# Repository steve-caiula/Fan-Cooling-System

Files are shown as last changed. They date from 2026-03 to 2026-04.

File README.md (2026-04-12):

# Fan Cooling System - Bare-Metal AVR

A bare-metal C project for the ATmega328P. Implements custom 1-Wire and I2C drivers, 
PWM fan control and tachometer reading via hardware timers and interrupts. No external libraries.

## Overview

This project implements a temperature-based fan cooling system on an ATmega328P microcontroller.
A DS18B20 sensor continuously measures the ambient temperature and adjusts the fan speed accordingly
via PWM, across four operating modes: Silent, Normal, Performance and Max. The system monitors fan RPM
via tachometer input and detects faults such as fan stall, underspeed and sensor disconnection.
Errors are signaled through a 20x4 I2C LCD display, a passive buzzer and four status LEDs, each with
a dedicated alarm priority. All drivers are implemented from scratch via direct register manipulation,
using only the avr-gcc toolchain.

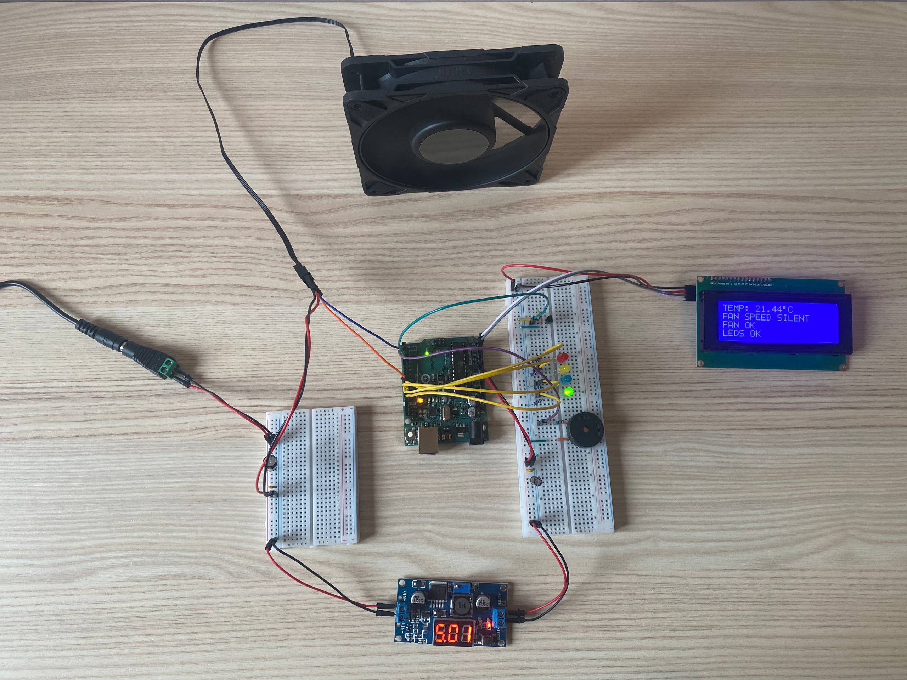
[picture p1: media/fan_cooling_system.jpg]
System


For the video demo, see the `media/` folder.

## Hardware

The system is built around an Arduino UNO R3 (ATmega328P) connected to a DS18B20 temperature sensor,
an Arctic P12 PRO PWM fan, a 20x4 I2C LCD display and a passive piezo buzzer. The circuit is powered
by a 12V supply with a DC-DC step-down module providing 5V to the MCU and peripherals. The fan is
driven directly at 12V. The circuit is currently assembled on a breadboard.

### Components

| **Component** | **Quantity** | **Notes** |
| :--- | :--- | :--- |
| Arduino UNO R3 | 1 | ATmega328P @ 16MHz |
| Arctic P12 PRO | 1 | 4-pin PWM fan, 12V |
| DS18B20 | 1 | 1-Wire temperature sensor |
| NHD-0420H1Z | 1 | 20x4 LCD with PCF8574 I2C module |
| Murata Buzzer | 1 | Passive piezo buzzer |
| LED | 4 | Red, Yellow, Blue, Green |
| DC-DC Step-Down Module | 1 | 12V → 5V (adjustable) |
| 12V Power Supply | 1 | |
| Capacitor 47µF 25V | 1 | Electrolytic, power supply decoupling |
| Capacitor 330µF 25V | 1 | Electrolytic, fan power decoupling |
| Capacitor 100nF | 2 | Ceramic, decoupling |
| Resistor 4.7kΩ | 1 | 1-Wire bus pull-up |
| Resistor 100Ω | 1 | Buzzer current limiting |
| Resistor 220Ω | 4 | LED current limiting |
| Breadboard | 2 | 830 tie points, 380 tie points |
| Jumper Wires | 22 | |

### Schematic

The KiCad project file and a PDF export are available in the `hardware/` folder.

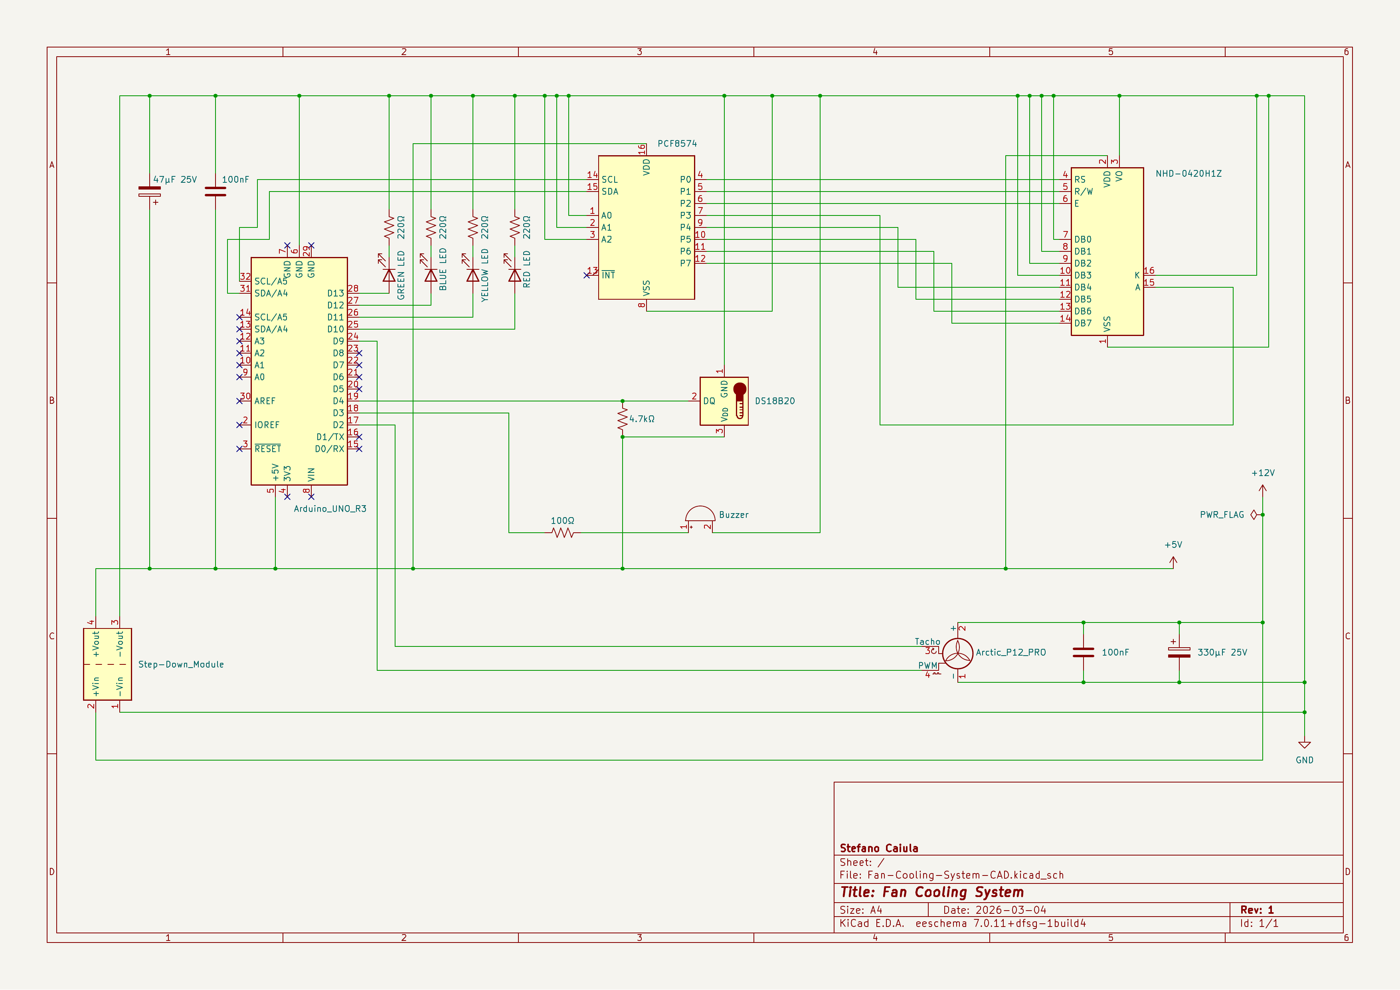
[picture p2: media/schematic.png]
Schematic


## Software

The firmware is organized into independent, single-responsibility modules. Each peripheral has a dedicated
driver with a clean public interface, keeping hardware-specific code separate from application logic.

### Structure

| **File** | **Description** |
| :--- | :--- |
| src/main.c | System initialization, main control loop, fault detection and alarm management  |
| src/fan.c | Arctic P12 PRO driver: 25kHz PWM, tachometer RPM sampling, fault detection |
| src/lcd.c | NHD-0420H1Z driver: TWI/I2C state machine, 4-bit mode, cursor control, print |
| src/temp_sensor.c | DS18B20 driver: 1-Wire protocol, non-blocking temperature conversion |
| src/buzzer.c | Passive buzzer driver: CTC tone generation, continuous and intermittent alarms  |
| src/led.c | LED status indicator driver: four-color fault signaling |
| src/system_timer.c | Timer0 CTC driver: 1ms interrupt-driven timekeeping via get_millis() |
| include/fan.h | Fan status enum, ICR1 value, public driver interface |
| include/lcd.h | TWI states, PCF8574 address, LCD commands, public driver interface |
| include/temp_sensor.h | DS18B20 commands, error sentinel, public driver interface |
| include/buzzer.h | OCR2A value formula, public driver interface |
| include/led.h | LED color enum, public driver interface |
| include/system_timer.h | OCR0A value, system_millis extern, public driver interface |
| include/board.h | Hardware pin definitions and CPU frequency for Arduino UNO R3 |
| include/config.h | System configuration parameters: temperature thresholds and fan speeds |
| Makefile | Build system: compile, flash and memory usage targets |

### Drivers and Communication Protocols  

The following section describes the drivers and communication protocols implemented 
in this project and the key implementation decisions.

#### Temperature Sensor - DS18B20 (1-Wire)

* **Reset and Presence Pulse:** Every communication starts with a 480µs reset pulse,
during which the master pulls the bus LOW. After release, the master samples at 70µs. 
The datasheet specifies that the sensor waits 15-60µs before pulling the bus LOW for 60-240µs. 
Sampling at 70µs ensures the presence pulse is detected for both fast sensors (15µs delay) 
and slow sensors (60µs delay), covering the full guaranteed window.
* **Write and Read Slots:** In a Write 1 slot the master pulls the bus LOW and releases
it within 15µs. The bus is pulled HIGH by the resistor for the remainder of the slot.
Holding for 10µs ensures the sensor detects the start but samples a HIGH state. In a
Write 0 slot the master holds the bus LOW for the full slot duration (minimum 60µs).
Holding for 55-60µs ensures the sensor samples a LOW state during its 15-60µs sampling
window. For Read slots, the master initiates with a 2µs LOW pulse, releases the bus and
samples at 12µs total from the falling edge, within the 15µs datasheet limit, providing
a safe margin.
* **Asynchronous Conversion:** The DS18B20 takes up to 750ms for a 12-bit conversion.
Instead of blocking the system with `_delay_ms(750)`, `get_raw_temperature()` implements
a two-state FSM using `get_millis()` to check elapsed time without occupying the CPU,
keeping the main loop responsive during conversion.

#### LCD - NHD-0420H1Z via PCF8574 (I2C)

* **Interrupt-Driven State Machine:** The TWI peripheral is driven by an ISR that manages
the I2C master transmitter state machine. Each transmission is triggered by writing to
TWCR with the START condition bit set. The ISR handles address transmission, data
transmission, NACK detection and bus release via STOP condition, setting `twi_busy = 0`
when complete. A timeout of 10ms in `twi_send()` prevents the system from blocking
indefinitely if the bus becomes unresponsive.

* **Bus Release Time:** After each STOP condition, a minimum delay of 50µs is required
before issuing a new START condition. Without this delay, the PCF8574 fails to
acknowledge the second transmission onward, causing `lcd_init()` to return an error.
This was identified during hardware testing and resolved by adding `_delay_us(50)` in
`twi_send()` after the bus-free check.

* **4-Bit Mode and EN Pulse:** Each byte is split into two nibbles, high nibble first,
then low nibble. For each nibble, two I2C bytes are sent: one with the EN pin HIGH to
latch the data, and one with EN LOW to complete the latch. The PCF8574 maps its 8 output
pins directly to the LCD control and data lines: P0=RS, P1=RW (always LOW), P2=EN,
P3=BL (backlight), P4-P7=DB4-DB7.

* **Initialization Sequence:** The LCD requires three wake-up nibbles (0x03) with
specific delays (>4.1ms, >100µs) before switching to 4-bit mode. This sequence is
mandatory, without it the controller does not correctly interpret subsequent commands.

* **Character Overflow Handling:** `lcd_print()` does not check the string length
before printing. A potential overflow would write to DDRAM beyond the last visible
character, but the NHD-0420H1Z has 40 DDRAM cells per row with non-contiguous
addresses between rows, so an overflow on one row does not corrupt the adjacent row.
All strings passed to `lcd_print()` are padded with trailing spaces to overwrite any
residual characters from previous prints, avoiding visual artifacts without calling
`LCD_CLEAR_DISPLAY` on every cycle, which would cause visible flickering due to the
1.52ms execution time of the clear command.

#### Fan - Arctic P12 PRO (PWM and Tachometer)

* **25kHz PWM Frequency:** Timer 1 is configured in Fast PWM mode 14 with ICR1 as TOP,
giving a frequency of 16MHz / 640 = 25kHz. This frequency follows the Intel 4-wire fan
specification and is above the audible range, ensuring silent operation at all duty
cycles. Fan speed is set by writing the duty cycle percentage (0-100) to OCR1A:
`OCR1A = (ICR1 * duty_cycle) / 100`.

* **RPM Sampling:** Tachometer pulses are counted by an INT0 ISR on the falling edge of
the tacho signal. `fan_get_rpm()` samples the pulse count every 1 second, calculates
RPM as `(elapsed_pulses / 2) * 60` (2 pulses per revolution), and returns the last
valid value between samples to keep the display stable.

* **Tachometer Pull-Up:** The Arctic P12 PRO tacho signal is open-collector. Without a
pull-up the pin floats and INT0 never triggers, resulting in RPM = 0. The ATmega328P
internal pull-up (~50kΩ) is enabled on the tacho pin via `PORTD |= (1 << FAN_TACHO)`,
providing a sufficient pull-up for the tachometer signal without external components.

* **Fault Detection:** `fan_get_status()` detects two fault conditions: stall (RPM = 0
with active PWM) and underspeed (RPM below the expected threshold calculated from duty
cycle, nominal RPM per duty unit and a configurable tolerance percentage). An upper
bound check on `FAN_RPM_MAX` discards parasitic readings caused by floating lines,
treating them as stall. Thresholds are configurable in `config.h`.

#### Buzzer - Murata Passive Piezo

* **CTC Tone Generation:** Timer 2 is configured in CTC mode to toggle OC2B (D3) on
compare match, generating a square wave at the target frequency. The compare value is
calculated as `OCR2A = (F_CPU / (2 * 64 * BUZZER_FREQ_HZ)) - 1`, where 64 is the
prescaler. At 2000Hz this gives OCR2A = 61, within the 8-bit range.

* **Continuous and Intermittent Alarms:** Two alarm modes are implemented. 
`buzzer_alarm_critical()` starts a continuous tone and locks it on until system reset,
subsequent calls are no-ops. `buzzer_alarm_warning()` implements a non-blocking
intermittent tone using `get_millis()` to alternate between on and off states based on
`BUZZER_BLINK_ON_MS` and `BUZZER_BLINK_OFF_MS` intervals defined in `config.h`.

* **Timer Reset Before Reconfiguration:** `buzzer_set_tone()` resets TCCR2A and TCCR2B
to 0 before reconfiguring Timer 2. Without this reset, residual timer state from a
previous `buzzer_alarm_critical()` call prevents the intermittent alarm from restarting
correctly after the critical alarm is cleared.

#### LED Status Indicators

* **Color-to-Fault Mapping:** Four LEDs on PB2-PB5 provide a visual summary of system
status: GREEN = all peripherals OK, YELLOW = sensor fault, RED = fan fault, BLUE = LCD
fault. At most one LED is active at any time, reflecting the highest-priority fault
currently detected.

* **Fault Priority:** RED and YELLOW take precedence over BLUE. When a critical fault
clears, the GREEN LED turns on and all others are turned off.

#### System Timer

`system_millis` is a `uint32_t`, which can hold values up to 2³²-1 = 4,294,967,295. Since it is incremented every millisecond by the
Timer0 ISR, it overflows after approximately 49.7 days:

$$\frac{2^{32} \text{ ms}}{\left( 1000 \frac{\text{ms}}{\text{s}} \cdot 60 \frac{\text{s}}{\text{min}} \cdot 60 \frac{\text{min}}{\text{h}} \cdot 24 \frac{\text{h}}{\text{d}} \right)} = \frac{4\,294\,967\,296 \text{ ms}}{86\,400\,000 \text{ ms/d}} \approx 49,7 \text{ d}$$

When overflow occurs, `system_millis` wraps back to 0. All elapsed-time checks in the codebase use the subtraction pattern
`current_time - last_time >= interval`, which is safe across overflow boundaries due to unsigned integer wraparound: if
`current_time` wraps to a value smaller than `last_time`, the subtraction underflows to the correct positive difference in modular
arithmetic. No special handling is therefore required.

### Error Handling

The system monitors four fault conditions and signals them through dedicated LEDs and
buzzer alarms. Faults are evaluated every main loop cycle and are mutually exclusive by
priority, sensor and fan faults take precedence over LCD and LED faults, preventing
lower-priority alarms from interfering with critical ones.

| **Fault** | **Detection** | **LED**  | **Buzzer** | **Fan** |
| :--- | :--- | :--- | :--- | :--- |
| Sensor error | `TEMP_SENSOR_ERROR` sentinel value | YELLOW | Continuous | MAX speed |
| Fan stall | RPM = 0 with active PWM | RED | Continuous | — |
| Fan underspeed | RPM below duty cycle threshold | RED | Continuous | — |
| LCD fault | TWI timeout or NACK | BLUE | Intermittent | — |
| LED fault | Invalid enum argument | — | Intermittent | — |

In safe mode, the fan is forced to MAX speed as a fail-safe measure: without a valid 
temperature reading, the system cannot determine the appropriate fan speed, so maximum 
cooling is applied to prevent overheating.

When all faults are cleared, the GREEN LED turns on and `buzzer_stop()` is called to
silence any active alarm.

### Critical Sections

* **Atomic 32-bit Read:** `system_millis` is a `uint32_t` updated by the Timer0 ISR
every 1ms. On an 8-bit architecture, reading a 32-bit variable requires 4 CPU cycles.
If the ISR fires mid-read, the value would be corrupted. `get_millis()` disables
interrupts with `cli()` for the duration of the read and re-enables them immediately
after with `sei()`.

* **1-Wire Timing Protection:** The 1-Wire protocol requires microsecond-level timing
precision. Any interrupt during a bit slot would corrupt the communication. `cli()` is
called at the start of every timing-critical operation (`sensor_reset()`,
`sensor_write_bit()`, `sensor_read_bit()`) and `sei()` is called immediately after,
keeping the critical section as short as possible.

### Problems and Resolutions

#### Blocking Delay During Temperature Conversion
Initially `get_raw_temperature()` used `_delay_ms(750)` to wait for the DS18B20
conversion, blocking the entire system for 750ms each cycle. As a solution, a two-state
FSM was implemented using `get_millis()` to check the elapsed time without occupying
the CPU, keeping the main loop responsive during conversion and ensuring all other
drivers continue to run normally.

#### False FAN_ERROR_STALL at Startup
At startup, `fan_get_rpm()` returns 0 for the first second because no tachometer sample
has been completed yet. With any active duty cycle, `fan_get_status()` would immediately
detect a stall condition and trigger the critical alarm. As a solution, a blocking wait
of 1 second is added after `sei()` in `main.c`:
```c
while (get_millis() < 1000);
```

This ensures the first RPM sample is ready before the main loop starts evaluating fan
status. Interrupts remain active during this wait, so all drivers continue to operate
normally.

#### I2C Bus Release Time
During hardware testing, `lcd_init()` consistently failed after the first nibble
transmission. The issue was identified in `twi_send()`, after each STOP condition
a new START was issued immediately without waiting for the bus to be released. The
PCF8574 requires a minimum settling time between STOP and the next START before it
can acknowledge a new transmission. As a solution, a `_delay_us(50)` was added in
`twi_send()` after the bus-free check, which resolved the issue completely.

#### Buzzer Warning Silenced After Critical Alarm
When the system transitions from a critical fault (sensor error or fan fault) to a
lower-priority fault (LCD error), `buzzer_alarm_warning()` is called with `buzzer_status`
still set to 1 from the previous `buzzer_alarm_critical()` call. The warning function
interprets this as an active tone and immediately calls `buzzer_stop()`, silencing the
buzzer without restarting the intermittent alarm. As a solution, `buzzer_set_tone()`
was modified to reset TCCR2A and TCCR2B to 0 before reconfiguring Timer 2, ensuring a
clean state regardless of the previous alarm mode.

#### LCD Flickering on Fan Fault
When a fan fault is detected, the main loop writes "FAN OK" to LCD row 2 inside the
temperature range blocks, then immediately overwrites it with the fault message inside
the fan error blocks. This double write on the same row every cycle causes visible
flickering. As a solution, the "FAN OK" print was moved inside a `if (fan_status == FAN_OK)`
check within each temperature range block, so row 2 is written only once per cycle
regardless of fan status.

#### False FAN_OK on Disconnected Power Lines
During hardware testing, disconnecting the fan power lines (VCC and GND) while leaving
the tacho and PWM cables connected caused fan_get_status() to return FAN_OK instead of
FAN_ERROR_STALL. The floating cables picked up electromagnetic noise, generating spurious
INT0 pulses that produced an artificially high RPM reading, masking the actual stall
condition. As a solution, an upper bound check was added in fan_get_status(): if RPM
exceeds FAN_RPM_MAX, the reading is treated as invalid and FAN_ERROR_STALL is returned.

### Known Limitations and Future Improvements

* **No hysteresis on temperature thresholds:** Rapid temperature fluctuations near a
threshold boundary may cause frequent fan speed changes. A hysteresis band around each
threshold would prevent this behavior and is planned for a future revision.

* **No fan-off mode for low temperatures:** The fan runs at minimum speed (30% duty
cycle) even at low temperatures. A fan-off mode with safe restart logic, ensuring the
fan reaches a stable speed before enabling fault detection, is planned for a future
revision.

* **No thermal protection on fan fault:** When a fan fault is detected, the system 
signals the error but has no hardware fallback to prevent overheating. In a production 
environment, a thermal shutdown or an emergency power-off mechanism should be considered.

* **Tachometer signal noise on breadboard:** The tachometer signal is occasionally susceptible 
to electromagnetic interference when the fan operates below approximately 80% duty cycle, where 
the lower motor current reduces the signal amplitude and makes it more vulnerable to noise induced 
by the breadboard's parasitic capacitance and unshielded connections. In affected conditions, 
spurious INT0 pulses may produce RPM readings that deviate from the actual fan speed. 
Migrating the circuit from breadboard to a perfboard or PCB, with shorter signal traces and 
more stable signal paths (and additional decoupling capacitors if necessary), is expected to 
resolve the issue.

### Installation and Usage

The following instructions are tested on Linux. See the Makefile comments for macOS and
Windows adjustments.

#### Prerequisites
The following tools are required: `avr-gcc`, `avr-libc` and `avrdude`.

On Debian-based systems:
```bash
sudo apt install gcc-avr avr-libc avrdude
```

#### Clone and Build
```bash
git clone https://github.com/steve-caiula/Fan-Cooling-System.git
cd Fan-Cooling-System
make
```

After a successful build, memory usage is printed automatically:
```
Program:    5270 bytes (16.1% Full)
(.text + .data + .bootloader)

Data:        297 bytes (14.5% Full)
(.data + .bss + .noinit)
```

#### Flash
Verify that the `PORT` variable in the Makefile matches your system before flashing.
Then run:
```bash
make flash
```

To remove build artifacts:
```bash
make clean
```

#### Configuration
System parameters such as temperature thresholds and fan speeds can be adjusted in
`include/config.h` without modifying the driver code.

Temperature thresholds are set to a compressed range (22–24°C) suitable for laboratory
testing with a soldering iron as heat source. For real-world use, widen the range in
`include/config.h` according to the target environment.

#### Usage
At startup the system waits 1 second for the first fan RPM sample, then enters the
main control loop. The LCD displays the current temperature and fan speed mode. If a
fault is detected, the corresponding LED turns on and the buzzer activates. The system
recovers automatically when the fault is cleared, except for fan stall and underspeed
which require a system reset.

## References

* [ATmega328P Datasheet](https://ww1.microchip.com/downloads/en/DeviceDoc/Atmel-7810-Automotive-Microcontrollers-ATmega328P_Datasheet.pdf)
* [DS18B20 Datasheet](https://www.analog.com/media/en/technical-documentation/data-sheets/DS18B20.pdf)
* [NHD-0420H1Z Datasheet](https://newhavendisplay.com/content/specs/NHD-0420H1Z-FSW-GBW-33V3.pdf)
* [PCF8574 Datasheet](https://www.nxp.com/docs/en/data-sheet/PCF8574_PCF8574A.pdf)
* [4-Wire PWM Fan Specification](https://glkinst.com/cables/cable_pics/4_Wire_PWM_Spec.pdf)
* [Arctic P12 PRO Documentation](https://support.arctic.de/p12-pro/docs)
* [Murata PKM22EPPH4001-BO Datasheet](https://www.arduino.cc/documents/datasheets/PIEZO-PKM22EPPH4001-BO.pdf)
* [Arduino UNO R3 Pinout](https://docs.arduino.cc/resources/pinouts/A000066-full-pinout.pdf)

## Author

Stefano Caiula
* [GitHub](https://github.com/steve-caiula)
* [LinkedIn](https://www.linkedin.com/in/stefano-c-a76137258/)

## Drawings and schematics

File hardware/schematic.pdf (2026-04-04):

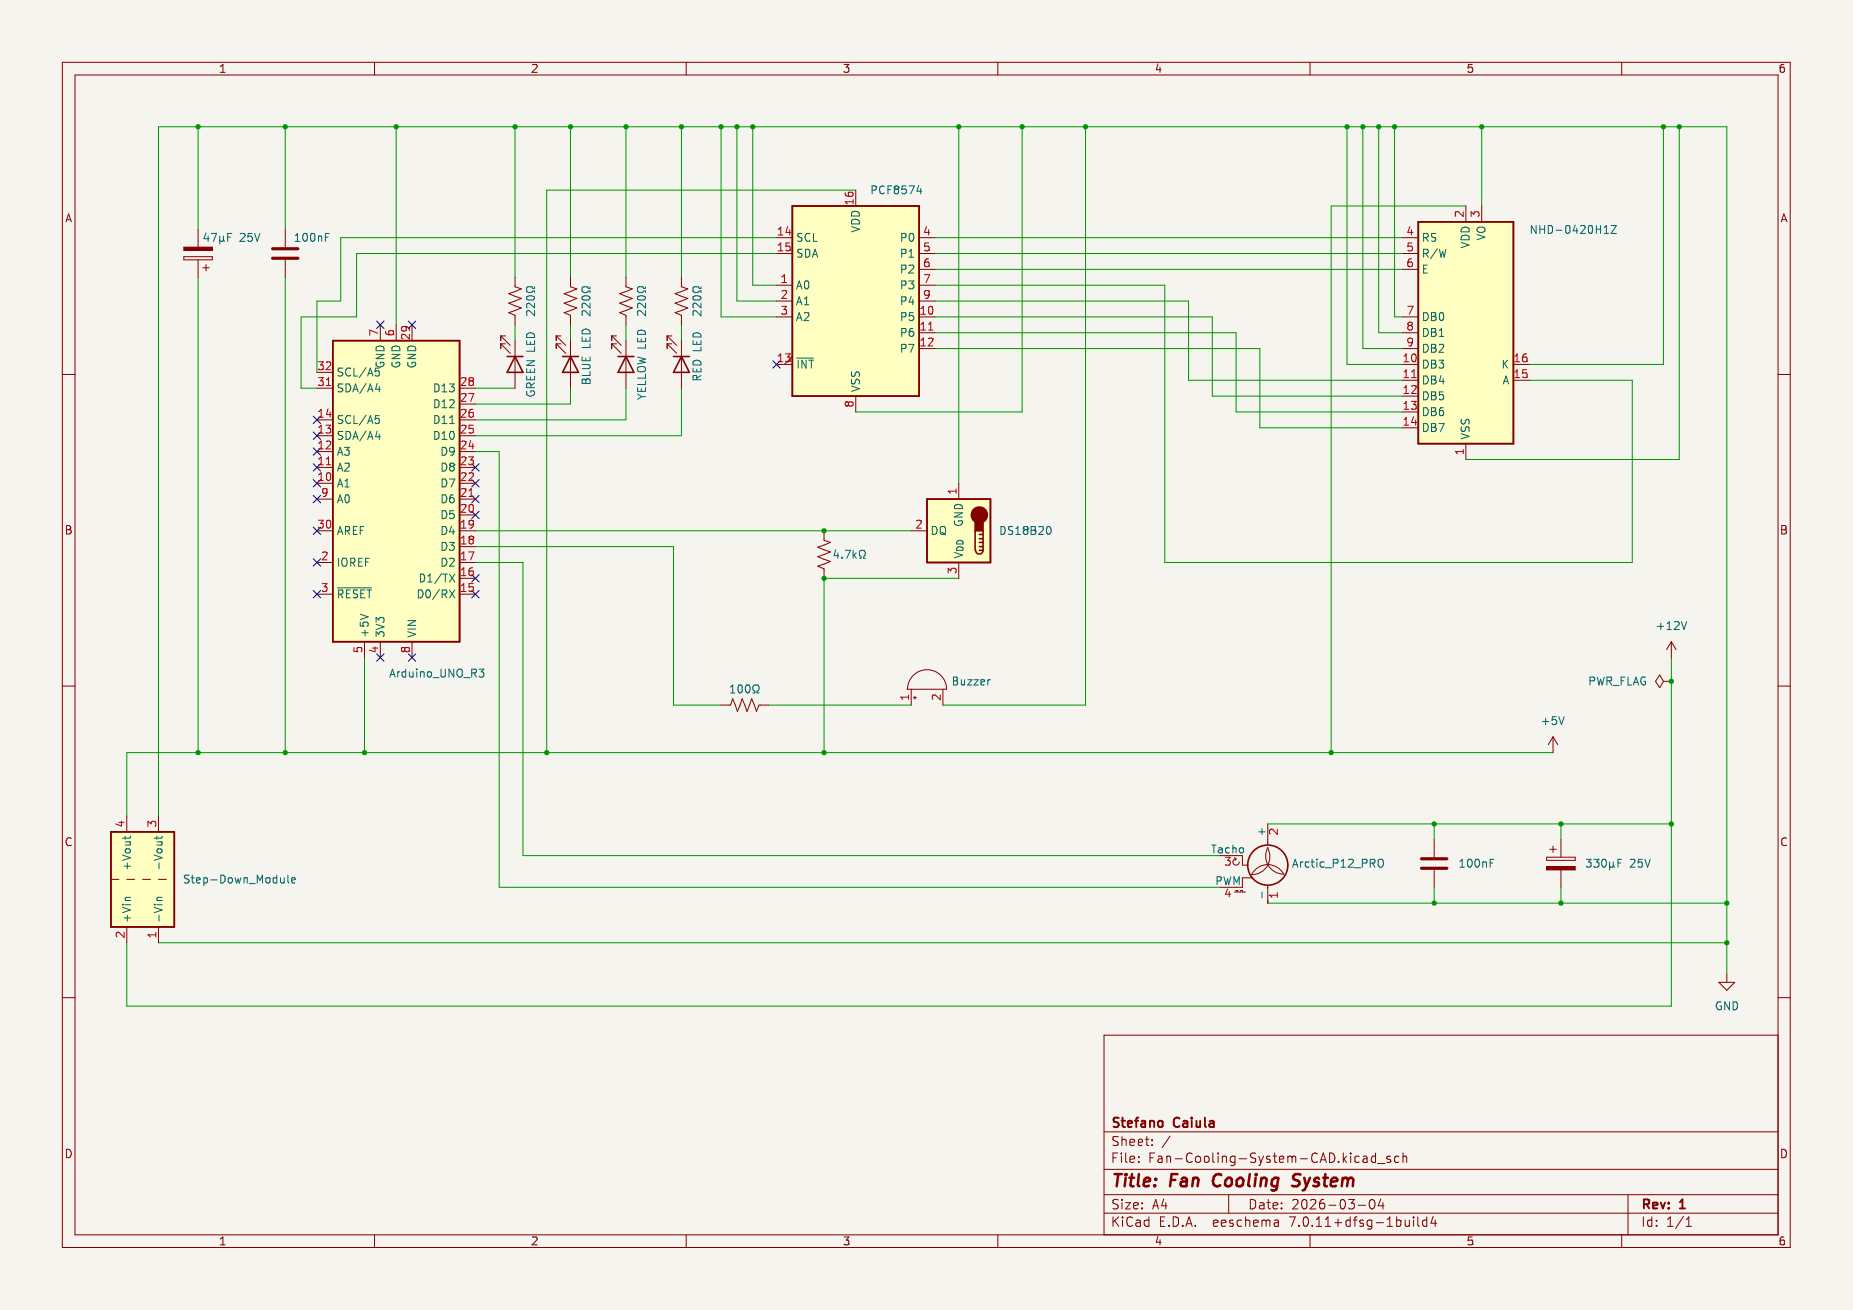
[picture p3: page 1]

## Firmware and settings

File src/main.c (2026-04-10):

/*
   Main control loop for a temperature-based fan cooling system.
   Reads temperature from a DS18B20 sensor and adjusts fan speed
   accordingly via PWM. Monitors fan RPM, LCD and LED status,
   and triggers alarms via buzzer and LEDs on fault detection.

   System parameters (temperature thresholds and fan speeds) are
   defined in config.h. Default values are calibrated for laboratory
   testing with a soldering iron.
   
   Hardware: Arduino UNO R3 (ATmega328P)
   Peripherals: DS18B20, Arctic P12 PRO, NHD-0420H1Z with PCF8574 I2C module, Murata buzzer
*/


#include <avr/interrupt.h>
#include <stdint.h>
#include <stdlib.h>
#include "fan.h"
#include "system_timer.h"
#include "temp_sensor.h"
#include "lcd.h"
#include "buzzer.h"
#include "led.h"
#include "config.h"


int main(void)
{
    int16_t raw_temperature;            // Raw temperature value from temperature sensor
    float temp_celsius;                 // Converted temperature in Celsius
    char temp_string[12];               // Buffer for temperature string conversion
    uint16_t rpm;                       // Fan speed in RPM
    fan_status_t fan_status = FAN_OK;   // Fan operational status, initialized to OK
    uint8_t duty_cycle;                 // Current fan duty cycle (percentage)
    uint8_t lcd_init_error = 0;         // LCD initialization error flag (1 = error)
    uint8_t lcd_error;                  // LCD operation error flag for current cycle
    uint8_t led_error = 0;              // LED operation error flag

    // Peripherals initialization
    system_timer_init();   // Must be called first: provides get_millis() to all drivers
    fan_init();            // Configures Timer 1 (PWM) and INT0 (TACHO)
    buzzer_init();         // Configures buzzer pin as output
    led_init();            // Configures LED pins as output

    sei();   // Enable global interrupts

    lcd_init_error = lcd_init();   // Initializes TWI and LCD, stores result for main loop

    while (get_millis() < 1000);   // Wait for fan RPM first sample to be ready to avoid FAN_ERROR_STALL in first loop

    while (1) 
    {   
        lcd_error = lcd_init_error;   // Reset LCD error flag, preserving init error if present
        
        raw_temperature = get_raw_temperature();              // Read raw temperature from temperature sensor
        temp_celsius = convert_to_celsius(raw_temperature);   // Convert to Celsius

        /*
           SAFE MODE: Sensor fault detected.
           Triggered when the temperature sensor is disconnected or malfunctioning.
           Fan is forced to maximum speed to guarantee cooling.
           LCD: displays sensor error and fan status.
           LED: YELLOW.
           Buzzer: continuous alarm.
        */
        if (raw_temperature == TEMP_SENSOR_ERROR) 
        {
            fan_set_speed(FAN_SPEED_MAX);
            
            duty_cycle = FAN_SPEED_MAX;
            rpm = fan_get_rpm();
            fan_status = fan_get_status(rpm, duty_cycle);
            
            lcd_error |= lcd_set_cursor(0, 0);
            lcd_error |= lcd_print("TEMP. SENSOR ERROR  ");
            lcd_error |= lcd_set_cursor(1, 0);
            lcd_error |= lcd_print("FAN SPEED MAX       ");

            if (fan_status == FAN_OK)
            {
                lcd_error |= lcd_set_cursor(2, 0);
                lcd_error |= lcd_print("FAN OK              ");
            }

            led_error |= led_off(RED);
            led_error |= led_on(YELLOW);
            led_error |= led_off(GREEN);
        }

        /*
           NORMAL OPERATION: Fan speed adjusted based on current temperature.
           - Below 25C:  SILENT mode      (30% duty cycle)
           - 25C to 30C: NORMAL mode      (50% duty cycle)
           - 30C to 35C: PERFORMANCE mode (75% duty cycle)
           - Above 35C:  MAX mode         (100% duty cycle)
           LCD: displays current temperature and fan speed mode.
           LED: RED off. Final state determined by fault checks below.
        */
        else 
        {
            lcd_error |= lcd_set_cursor(0, 0);
            lcd_error |= lcd_print("TEMP: ");
            dtostrf(temp_celsius, 4, 2, temp_string);
            lcd_error |= lcd_print(temp_string);
            lcd_error |= lcd_send_byte(LCD_DEGREE_SYMBOL, LCD_DATA);
            lcd_error |= lcd_print("C       ") ;

            led_error |= led_off(YELLOW);

            if (temp_celsius <= FAN_TEMP_SILENT) 
            {
                fan_set_speed(FAN_SPEED_SILENT);
            
                duty_cycle = FAN_SPEED_SILENT;
                rpm = fan_get_rpm();
                fan_status = fan_get_status(rpm, duty_cycle);
            
                lcd_error |= lcd_set_cursor(1, 0);
                lcd_error |= lcd_print("FAN SPEED SILENT    ");

                if (fan_status == FAN_OK)
                {
                    lcd_error |= lcd_set_cursor(2, 0);
                    lcd_error |= lcd_print("FAN OK              ");
                }

                led_error |= led_off(RED);
            }

            else if (temp_celsius <= FAN_TEMP_NORMAL) 
            {
                fan_set_speed(FAN_SPEED_NORMAL);
            
                duty_cycle = FAN_SPEED_NORMAL;
                rpm = fan_get_rpm();
                fan_status = fan_get_status(rpm, duty_cycle);

                lcd_error |= lcd_set_cursor(1, 0);
                lcd_error |= lcd_print("FAN SPEED NORMAL    ");

                if (fan_status == FAN_OK)
                {
                    lcd_error |= lcd_set_cursor(2, 0);
                    lcd_error |= lcd_print("FAN OK              ");
                }

                led_error |= led_off(RED);
            }

            else if (temp_celsius <= FAN_TEMP_PERFORMANCE) 
            {
                fan_set_speed(FAN_SPEED_PERFORMANCE);
            
                duty_cycle = FAN_SPEED_PERFORMANCE;
                rpm = fan_get_rpm();
                fan_status = fan_get_status(rpm, duty_cycle);

                lcd_error |= lcd_set_cursor(1, 0);
                lcd_error |= lcd_print("FAN SPEED PERFORM.  ");
        
                if (fan_status == FAN_OK)
                {
                    lcd_error |= lcd_set_cursor(2, 0);
                    lcd_error |= lcd_print("FAN OK              ");
                }

                led_error |= led_off(RED);
            }

            else
            {
                fan_set_speed(FAN_SPEED_MAX);
            
                duty_cycle = FAN_SPEED_MAX;
                rpm = fan_get_rpm();
                fan_status = fan_get_status(rpm, duty_cycle);

                lcd_error |= lcd_set_cursor(1, 0);
                lcd_error |= lcd_print("FAN SPEED MAX       ");

                if (fan_status == FAN_OK)
                {
                    lcd_error |= lcd_set_cursor(2, 0);
                    lcd_error |= lcd_print("FAN OK              ");
                }

                led_error |= led_off(RED);
            }
        }

        /*
           FAN STALL: Critical fault. Fan is not spinning despite active PWM signal.
           Cooling cannot be guaranteed. System requires immediate intervention.
           LCD: displays stall error and cooling failure warning.
           LED: RED on.
           Buzzer: continuous alarm.
        */
        if (fan_status == FAN_ERROR_STALL)
        {
            led_error |= led_on(RED);
            led_error |= led_off(GREEN);
            buzzer_alarm_critical();
        
            lcd_error |= lcd_set_cursor(1, 0);
            lcd_error |= lcd_print("FAN ERROR STALL     ");
            lcd_error |= lcd_set_cursor(2, 0);
            lcd_error |= lcd_print("COOLING FAILURE!    ");
        }

        /*
           FAN UNDERSPEED: Critical fault. Fan is spinning below the required speed.
           Cooling is active but may be insufficient for current temperature.
           System requires inspection.
           LCD: displays underspeed error and inspection warning.
           LED: RED on.
           Buzzer: continuous alarm.
        */
        else if (fan_status == FAN_ERROR_UNDERSPEED) 
        {
            led_error |= led_on(RED);
            led_error |= led_off(GREEN);
            buzzer_alarm_critical();

            lcd_error |= lcd_set_cursor(1, 0);
            lcd_error |= lcd_print("FAN ERROR UNDERSPEED");
            lcd_error |= lcd_set_cursor(2, 0);
            lcd_error |= lcd_print("CHECK THE FAN!      ");
        }

        /*
           LCD FAULT: Communication error with the LCD display.
           Triggered when the LCD is disconnected or malfunctioning.
           LED: BLUE on.
           Buzzer: intermittent alarm, only if no critical faults are active
           (sensor error and fan faults have priority).
        */
        if (lcd_error == 1)
        {
            if (raw_temperature != TEMP_SENSOR_ERROR && fan_status == FAN_OK) 
            {
                buzzer_alarm_warning();
            }
        
            led_error |= led_on(BLUE);
            led_error |= led_off(GREEN);
        }

        else
        {
            led_error |= led_off(BLUE);
        }

        /*
           LED FAULT: Error detected in LED operation.
           In practice this fault should never occur, as LED functions are
           always called with valid led_color_t enum values.
           Included as a defensive check against future code changes.
           LCD: displays LED error on row 4.
           Buzzer: intermittent alarm, only if no critical faults are active
           (sensor error and fan faults have priority).
        */
        if (led_error == 1)
        {
            if (raw_temperature != TEMP_SENSOR_ERROR && fan_status == FAN_OK) 
            {
                buzzer_alarm_warning();
            }
        
            lcd_error |= lcd_set_cursor(3, 0);
            lcd_error |= lcd_print("LEDS ERROR          ");
        }

        else 
        {
            lcd_error |= lcd_set_cursor(3, 0);
            lcd_error |= lcd_print("LEDS OK             ");
        }

        /*
           ALL PERIPHERALS OK: No faults detected. GREEN LED on.
        */
        if (fan_status == FAN_OK && raw_temperature != TEMP_SENSOR_ERROR && lcd_error == 0 && led_error == 0)
        {
            led_error |= led_on(GREEN);
            led_error |= led_off(BLUE);
            led_error |= led_off(YELLOW);
            led_error |= led_off(RED);

            buzzer_stop();
        }
    }
}

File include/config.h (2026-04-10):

/*
   System configuration parameters.
   Modify these values to adapt the system to your specific use case.
   Default values are calibrated for laboratory testing with a soldering iron.
*/

#ifndef CONFIG_H
#define CONFIG_H


// BUZZER
#define BUZZER_FREQ_HZ         2000   // Tone frequency
#define BUZZER_BLINK_ON_MS     200    // Time sound on
#define BUZZER_BLINK_OFF_MS    200    // Time sound off


// FAN
#define FAN_RPM_PER_DUTY       18     // 1800 RPM max / 100
#define FAN_SPEED_TOLERANCE    50     // Minimum acceptable RPM percentage


// TEMPERATURE THRESHOLDS
// Compressed range (22-24°C) calibrated for laboratory testing with a soldering iron.
// Widen the range for real-world use cases.
#define FAN_TEMP_SILENT        22     // Below 22°C
#define FAN_TEMP_NORMAL        23     // 22.01°C - 23°C
#define FAN_TEMP_PERFORMANCE   24     // 23.01°C - 24°C (above 24°C -> safe mode)


// FAN SPEED
#define FAN_SPEED_SILENT       30     // Mode SILENT (minimum guaranteed speed)
#define FAN_SPEED_NORMAL       50     // Mode NORMAL
#define FAN_SPEED_PERFORMANCE  75     // Mode PERFORMANCE
#define FAN_SPEED_MAX          100    // Mode MAX or safe mode (temp. sensor error)


#endif

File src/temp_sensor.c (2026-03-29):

/*
   Temperature sensor driver for DS18B20 on 1-Wire bus (D4).
   Implements bit-banged 1-Wire protocol with interrupt protection.
   Communication slots use blocking delays (~2ms total).
   Temperature conversion (750ms) is non-blocking via state machine.
*/


#include <avr/io.h>
#include <avr/interrupt.h>
#include <util/delay.h>
#include "temp_sensor.h"
#include "board.h"
#include "system_timer.h"


uint8_t sensor_reset(void)
{
    uint8_t detected = 0;

    cli();   // Critical Section Start: Disable interrupts to protect 1-Wire timing

    // PHASE 1: MASTER TRANSMITS RESET PULSE

    DDRD |= (1 << TEMP_SENSOR);     // Set pin as output
    PORTD &= ~(1 << TEMP_SENSOR);   // Pull bus LOW
    _delay_us(480);             // Wait time for reset 

    // PHASE 2: MASTER REALESES BUS AND WAITS FOR PRESENCE PULSE

    DDRD &= ~(1 << TEMP_SENSOR);   // Release bus (set as input)
    
    /* 
       Wait 70us to sample the bus.
       The datasheet states that the sensor waits 15-60us before pulling the bus LOW
       for 60-240us. Sampling at 70us ensures we catch both fast and slow sensors
       during their guaranteed presence pulse window.
    */
    _delay_us(70);

    // PHASE 3: SAMPLE THE BUS TO DETECT THE SENSOR

    if (!(PIND & (1 << TEMP_SENSOR))) 
    {
        detected = 1;   // Sensor pulled the bus LOW (Presence Pulse found)
    }

    else 
    {
        detected = 0;
    }

    /* 
       Recovery time: Wait for the remainder of the 480us time slot.
       This ensures the sensor has finished its presence pulse (max 240us)
       and the bus has stabilized before the next communication starts.
    */
    _delay_us(410);  
    
    sei();   // Critical Section End: Re-enable interrupts

    return detected;   // Return 1 if the sensor is detected, 0 otherwise
}


/*
   Sends a single bit on the 1-Wire bus.
   Disables interrupts to protect timing-sensitive write slot.
*/
static void sensor_write_bit(uint8_t bit_value)
{
    cli();   // Atomic Block Start: Prevent interrupt interference during write slot
    
    // Every write slot starts by pulling the bus LOW
    DDRD |= (1 << TEMP_SENSOR);    // Set pin as output
    PORTD &= ~(1 << TEMP_SENSOR);  // Pull bus LOW
    
    /* 
       Write 1 slot: The master pulls the bus LOW and then releases it 
       within 15us. The bus is pulled HIGH by the resistor for the 
       remainder of the slot. Holding for 10us ensures the sensor 
       detects the start but samples a HIGH state.
    */
    if (bit_value) 
    {
        _delay_us(10);             // Keep bus LOW for short amount of time
        DDRD &= ~(1 << TEMP_SENSOR);   // Release bus (set as input)
        _delay_us(50);             // Recovery time
    }

    /* 
       Write 0 slot: The master pulls the bus LOW and holds it for 
       the duration of the slot (minimum 60us). Holding for 55-60us 
       ensures the sensor samples a LOW state during its 15-60us window.
    */
    else 
    {
        _delay_us(55);             // Keep bus LOW for almost the whole slot time
        DDRD &= ~(1 << TEMP_SENSOR);   // Release bus (set as input)
        _delay_us(5);              // Recovery time
    }

    sei(); // Atomic Block End

    /* 
       Global recovery time: The dasheet states that the sensor needs a
       minimum of a 1us recovery time between individual write slots.
    */
    _delay_us(2);   // This ensures at least 2us of HIGH bus between any two bits
}


/*
   Sends a full byte LSB-first on the 1-Wire bus.
*/
static void sensor_write_byte(uint8_t data)
{
    // Loop 8 times to read each bit of the byte
    for (uint8_t i = 0; i < 8; i++) 
    {
        sensor_write_bit(data & 0x01);   // Isolate bit
        data >>= 1;                                // Shift bit
    }
}


/*
   Reads a single bit from the 1-Wire bus.
   Disables interrupts to protect the 15us sampling window.
   Returns the bit value (0 or 1).
*/
static uint8_t sensor_read_bit(void)
{
    uint8_t bit_value = 0;

    cli();   // Atomic Block Start: Protect the timing-sensitive sampling window

    /* 
       Every read slot is initiated by the master pulling the bus LOW 
       for a minimum of 1us. We hold it for 2us to ensure the sensor 
       detects the start of the slot (TINIT).
    */
    DDRD |= (1 << TEMP_SENSOR);     // Set pin as output
    PORTD &= ~(1 << TEMP_SENSOR);   // Pull bus LOW
    _delay_us(2);

    /* 
       After the initial pulse, the master must release the bus so the 
       sensor can take control. We then wait for the signal to stabilize.
       The datasheet states data is valid for 15us from the start of the slot.
    */
    DDRD &= ~(1 << TEMP_SENSOR);   // Release bus (set as input)
    _delay_us(10);

    /* 
       The master must sample within 15us from the falling edge. 
       Having already waited 2us, an additional 10us delay brings us 
       to 12us total. This provides a safety margin, sampling just 
       before the 15us limit (TSAMPLE).
    */
    if (PIND & (1 << TEMP_SENSOR))
    {
        bit_value = 1;
    }

    // else: do nothing as the bit is already 0 by default

    /* 
       The total time slot must be at least 60us. 
       We wait the remaining time (approx 50us) to complete the slot 
       and allow the mandatory recovery time before the next operation.
    */
    _delay_us(50);

    sei();   // Atomic Block End

    /* 
       Global recovery time: The datasheet states a minimum of 1us 
       is required between individual slots to let the bus stabilize.
    */
    _delay_us(2);

    return bit_value;
}


/*
   Reads a full byte LSB-first from the 1-Wire bus.
   Returns the assembled byte from 8 consecutive read slots.
*/
static uint8_t sensor_read_byte(void)
{
    uint8_t scratchpad_byte = 0;   // Temporary container for the received byte

    // Loop 8 times to read each bit of the byte
    for (uint8_t i = 0; i < 8; i++) 
    {
        uint8_t bit = sensor_read_bit();
        
        if (bit == 1) 
        {
            // The DS18B20 transmits the Least Significant Bit (LSB) first
            scratchpad_byte |= (1 << i);   // Set the i-th bit of scratchpad_byte
        }

        // else: do nothing as the bit is already 0 by default
    }

    return scratchpad_byte;
}
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

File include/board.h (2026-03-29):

/*
   Hardware pin definitions and CPU frequency for Arduino UNO R3.
   Modify this file when porting to a different board.
*/


#ifndef BOARD_H
#define BOARD_H


// BUZZER PIN
#define BUZZER  PD3


// SENSOR PIN
#define TEMP_SENSOR  PD4


// FAN PINS
#define FAN_PWM    PB1
#define FAN_TACHO  PD2


// LCD PINS
#define LCD_SDA  PC4
#define LCD_SCL  PC5


// LED PINS
#define LED_RED     PB2
#define LED_YELLOW  PB3
#define LED_BLUE    PB4
#define LED_GREEN   PB5


// CPU FREQUENCY
#define CPU_FREQ  16000000UL


#endif

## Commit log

2026-03-04 hw: add schematic
    [hardware.kicad_sch]
2026-03-10 hw: update schematic
    [schematic.kicad_sch]
2026-03-16 Add TWI driver skeleton with ISR structure and buffer variables
2026-03-19 Add TWI driver: init, send functions and ISR with buffer management
2026-03-24 drv(lcd): basic init and write functions (error handling pending)
    [lcd.c, lcd.h]
2026-03-25 hw: update schematic, sw: update pin_definitions.h
    [schematic.kicad_sch]
2026-03-26 feat: complete buzzer driver
    [temp_sensor.c]
2026-03-26 add robust error handling to lcd driver
    [lcd.c, lcd.h]
2026-03-27 add fan driver skeleton
2026-03-27 add fan driver pwm and tacho implementation
2026-03-28 complete fan driver and project structure refactoring
2026-03-28 refactor buzzer driver with improved structure and documentation
    [board.h, config.h, fan.c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]
2026-03-29 add status LEDs to schematic and board configuration
    [schematic.kicad_sch]
2026-03-29 add LED status indicator driver
2026-03-29 add comments to fan driver
2026-03-29 add lcd driver comments
2026-03-29 add temp sensor driver comments
2026-03-29 add system timer comments
2026-03-29 add led driver comments
2026-03-29 add board.h comments
2026-04-03 correct main and lcd driver
    [lcd.c, main.c]
2026-04-04 hw: update schematic, sw: update main, config, fan, buzzer, lcd
    [schematic.kicad_sch]
2026-04-10 correct fan mode in main, change config, correct readme
    [config.h, main.c]
2026-04-10 fan.c: handle parasitic noise/floating ground caused by disconnected power lines
    [fan.c]
2026-04-10 update fan, config, readme
